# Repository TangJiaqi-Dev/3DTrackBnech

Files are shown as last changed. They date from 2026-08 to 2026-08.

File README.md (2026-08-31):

# 3DTrackBench Documentation

3DTrackBench is a standardized framework for benchmarking Extended Reality (XR) and surgical tracking systems using consumer 3D printers as deterministic motion platforms. In this experiment we would like to validate this accross different 3D printers and international collaborators. Thank you for participating! 

## Core Principle
Consumer 3D printers offer sub-millimeter positioning accuracy ($<0.1$ mm) at low cost. By mounting tracking markers to the extruder and executing a standardized G-code trajectory, the printer serves as a high-fidelity ground truth generator. 

## Validated Metrics
The analysis pipeline quantifies:
* **Static Jitter:** Stability during zero-velocity holds.
* **Spatial Accuracy:** RMSE against analytical ground truth (Linear, Circular, Complex).
* **Latency:** End-to-end system delay (optional module).
* **Robustness:** Tracking loss and drop rates under high-velocity stress.
* **Drift:** Tracking drift over time.

---

# Hardware Setup & Prerequisites

## 1. Required Materials

| Component | Specification | Notes |
| :--- | :--- | :--- |
| **3D Printer** | See '/Materials' for validated printers. | Minimum build volume: $180 \times 180 \times z$ mm. |
| **Tracker** | Any NDI optical tracker. | Custom tracking systems are supported; contact the PI for integration. |
| **Markers** | NDI standard passive marker. | If no official tool, ensure tool registration within NDI software. |
| **Mounting** | Standard NDI mount + 3D printed adapter. | See `/Materials` for models. If standard mounts are incompatible and you need help, contact PI. |
| **Fasteners** | Zip ties. | Required to eliminate mechanical play between extruder and mount. Feel free to use any other rigid option. |

## 2. Adapter Fabrication
1.  **File Selection:** Navigate to `/Materials` and select the adapter matching your printer model and mount type.
2.  **Material:** Use any rigid filament. Recommended but not mandatory to use **Matte Black PLA** to prevent specular reflections from interfering with optical tracking.
3.  **Slicer Settings:** Set infill to a value between 35% and 45% to ensure structural rigidity and use a (outside-)brim to prevent any warping.

## 3. Physical Installation
1.  **Attach Mount:** Secure the printed adapter to the printer head. The connection must be rigid; any vibration or play invalidates metrics. Use zip ties if rigid mounting points are unavailable. Examples of how to fasten the zipties can be found in `/Materials`.
2.  **Affix Markers:** Attach the NDI marker to the adapter using a standard NDI clamp. Ensure the marker plane is **parallel** to the printer's X-axis motion (see reference image).
3.  **Clearance Check:** Manually move the print head to the volume limits to verify zero collision with the frame or bed.

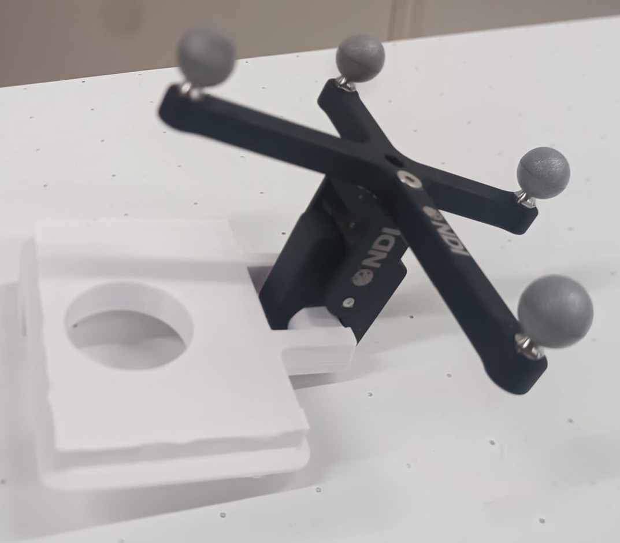
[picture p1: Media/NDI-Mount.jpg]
NDI Mount


## 4. Environmental Standardization
* **Lighting:** Use standard laboratory ceiling lighting. Eliminate direct sunlight.

---

# Benchmark Execution

**WARNING**: Read the readme file in your printer's folder for model-specific safety instructions.

## 5. Tracker Placement
1.  **Printer Stabilization:** Place the printer on a vibration-free platform.
2.  **Load G-code:** Copy the specific G-code files for your printer model to a microSD card or USB drive.
    > **CRITICAL:** Only run G-code generated specifically for your printer model. Mismatched G-code may cause hardware failure.
    > Need a different travel range or feedrate than the shipped file? See [Generating a Custom Benchmark File](#generating-a-custom-benchmark-file) below instead of editing a `.gcode` file by hand.
3.  **Run Placement Script:** Execute `placement.gcode`. This moves the extruder to the center of the tracking volume.
4.  **Align Tracker:** Position the NDI optical tracker perpendicular to the print head at a distance so that the marker is detected in the middle of the NDI standard volume (the smaller box)

## 6. Data Acquisition
1.  **Configure NDI:** Set the NDI recording framerate to the maximum available (minimum $\geq 60$ Hz).
2.  **Execute Benchmark:**
    * Select `Benchmarkv01ext - <your printer> -20251221.gcode` on the printer.
    * **Deselect** automated calibration features (e.g., bed leveling, flow calibration) before starting.
    * Start the NDI recording before starting the execution of the gcode on the printer.
3.  **Completion:** The sequence lasts 6–10 minutes. Stop the NDI recording once the printer signals completion.
4.  **Rerun:** Run the sequence and recording two more times, to end up with 3 measurements.
5.  **Upload the results:** Forward the final results to the PI at `hizirwan.salim@surf.nl

---

# Generating a Custom Benchmark File

The files under `/Materials` trace a fixed 178mm box at a fixed speed sweep. If you need a
different travel range or feedrate — e.g. to test a smaller working volume, or to check
tracking at a narrower speed band — `tools/gcode_generator.py` generates a new `.gcode`
file with those parameters instead of editing one by hand.

```
pip install pyyaml
python tools/gcode_generator.py --printer a1_mini --x-range 40 140 --z-range 40 140 --out out.gcode
```

Supports `a1_mini`, `x1c`, and `h2d` (`--printer`). Requested ranges/speeds are validated
against each printer's physical limits in `printer_profiles.yaml` and rejected if unsafe.
See [tools/README.md](tools/README.md) for the full flag reference.

---

Big thanks for testing 3DTrackBench! Your data is essential for validating this framework. If you run into any issues or have ideas for improvement, don't hesitate to reach out. If you would like to see the results of your own dataset, use the tooling we made below.

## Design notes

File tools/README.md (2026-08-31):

# G-code generator

Generates a 3DTrackBench benchmark `.gcode` file with an adjustable travel
range and speed range, instead of the fixed 180x180mm / F6000-F30000 ranges
baked into the files under `/Materials`.

Supports **A1 mini** (`a1_mini`), **X1 Carbon** (`x1c`), and **H2D** (`h2d`)
— see `printer_profiles.yaml`. A1 mini's toolhead moves in X/Z (Y is the
bed); X1C and H2D are CoreXY and move in X/Y (Z only lifts the bed), so
their range flags are `--x-range`/`--y-range` instead. Adding another
printer means adding a profile entry plus a `templates/<id>/{start,end}.gcode`
pair extracted from a real sliced file for that machine — no code changes.

## Setup

```
pip install pyyaml
```

## Usage

Reproduce the shipped file's default range and speed sweep:

```
python tools/gcode_generator.py --printer a1_mini --out out.gcode
```

Restrict the travel range and/or speed sweep:

```
python tools/gcode_generator.py --printer a1_mini \
  --x-range 40 140 --z-range 40 140 \
  --speed-range 6000 12000 --speed-step 3000 \
  --out out.gcode
```

Flags:
- `--printer` — printer id from `printer_profiles.yaml`: `a1_mini`, `x1c`,
  or `h2d` (default `a1_mini`).
- `--x-range MIN MAX` / `--y-range MIN MAX` / `--z-range MIN MAX` — travel
  range in mm for whichever two axes the printer's toolhead actually moves
  in; passing a range for its bed axis (Y on a1_mini, Z on x1c/h2d) is
  rejected with an error. Omit an axis to center the shipped files' default
  178mm box inside that printer's build volume.
- `--speed-range START END` — feedrate range in mm/min (G-code `F` units,
  e.g. `6000` = 100 mm/s) for the `speed_sweep` phase specifically.
- `--speed-step` — `speed_sweep`'s feedrate step size (default `3000`).
- `--seed` — RNG seed for the scattered-point sections (calibration,
  complex path). Same seed + same range always produces the same points.
- `--out` — output `.gcode` path (required).

`--speed-range`/`--speed-step` only control the `speed_sweep` phase (the
one that repeats a shuttle move at increasing feedrates). The other five
phases each move at their own fixed feedrate — these came from the shipped
A1 mini file with no documented rationale for the specific numbers, so
they're also exposed as flags rather than left hard-coded:

- `--speed-sweep-warmup` — `speed_sweep`'s warm-up feedrate (default `3000`).
- `--calibration-speed` — `calibration`'s corner-move feedrate (default `3000`).
- `--linear-speed` — `linear`'s feedrate (default `6000`).
- `--circular-travel-speed` — `circular`'s approach-move feedrate, before it
  starts tracing the arc (default `2000`).
- `--circular-speed` — `circular`'s arc-tracing feedrate (default `6000`).
- `--complex-speed` — `complex`'s feedrate (default `6000`).
- `--drift-speeds V1 V2 ...` — `drift`'s feedrates, one shuttle pass per
  value (default `3000 6000`).

All feedrate flags are validated against the printer's `max_speed_mm_s` and
rejected if they exceed it, same as `--speed-range`.

Requests that exceed the printer's build volume or max speed
(`printer_profiles.yaml`) are rejected with an error rather than silently
clamped, since running an out-of-range file risks a crash into the frame or
an endstop. A narrower range than the printer's default margin recommends
prints a warning but is still allowed.

## What it generates

The output has the same structure as the shipped files: printer-specific
start/end boilerplate (from `templates/<printer>/`, extracted verbatim from
Bambu Studio) wrapping a benchmark body with these phases, each ending in a
`G4` pause for static hold measurements:

1. **calibration** — static points scattered across the range (jitter).
2. **linear** — a corner-to-corner straight-line sweep (spatial accuracy).
3. **circular** — a full loop around the range's center (spatial accuracy).
4. **speed_sweep** — repeated shuttle moves at each feedrate in the
   configured speed range (robustness at speed).
5. **complex** — scattered points confined to a sub-region (stress test).
6. **drift** — repeated shuttle moves at increasing speed, single-axis then
   diagonal (drift / robustness).

The scattered-point sections use a seeded RNG rather than reproducing the
shipped file's exact coordinates (those came from an unpublished script),
so output is reproducible per seed but not byte-identical to the files
under `/Materials`.

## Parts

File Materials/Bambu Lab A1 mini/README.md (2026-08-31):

# Bambu Lab A1 mini files
Last updated: 11/01/2026

For the Bambu Lab A1, remove the front cover and the yellow rotating extruder indicator. 
If you have the original NDI markers and clamp mount, attach as shown below:

NDI Mount

Shown below is a 'screw on' faceplate for the Atracsys Tindax 305 marker.

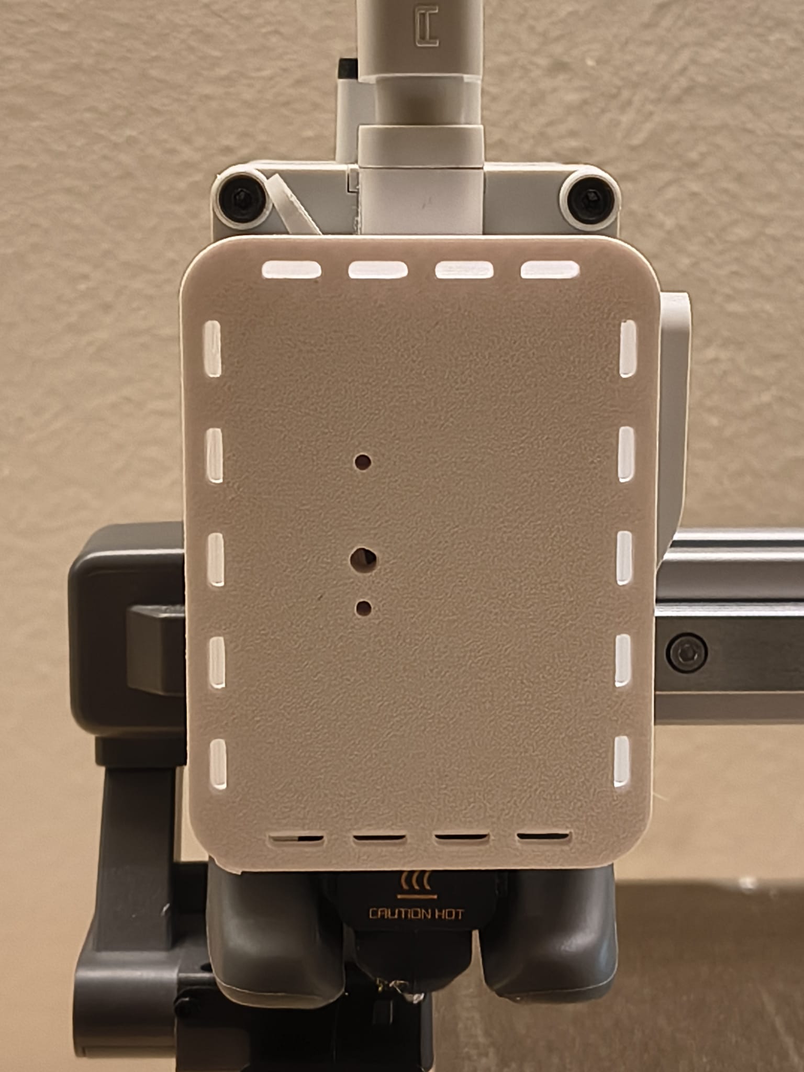
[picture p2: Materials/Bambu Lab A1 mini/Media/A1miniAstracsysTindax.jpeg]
Atracsys Tindax 305 Faceplate


The images below demonstrate how to secure the mount using zip ties. Any method of fixating the markers to the extruder that eliminates all (sub-mm)wobble is sufficient. This is just an example.

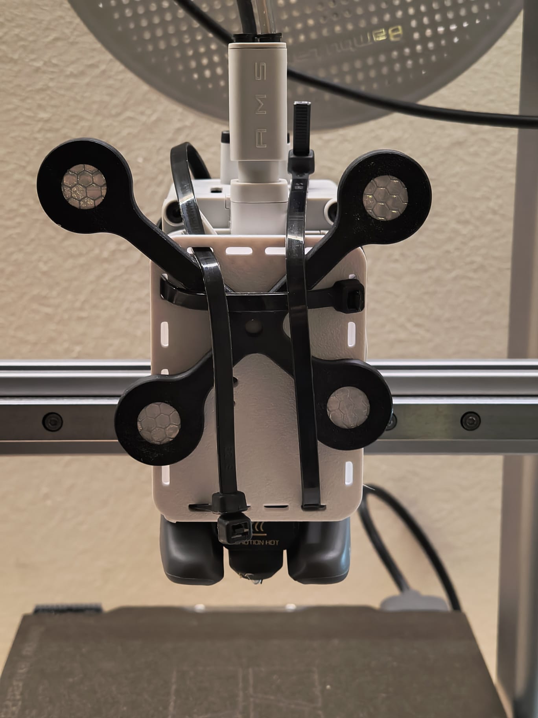
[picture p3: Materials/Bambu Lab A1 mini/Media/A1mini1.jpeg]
Zip Tie Mounting 1

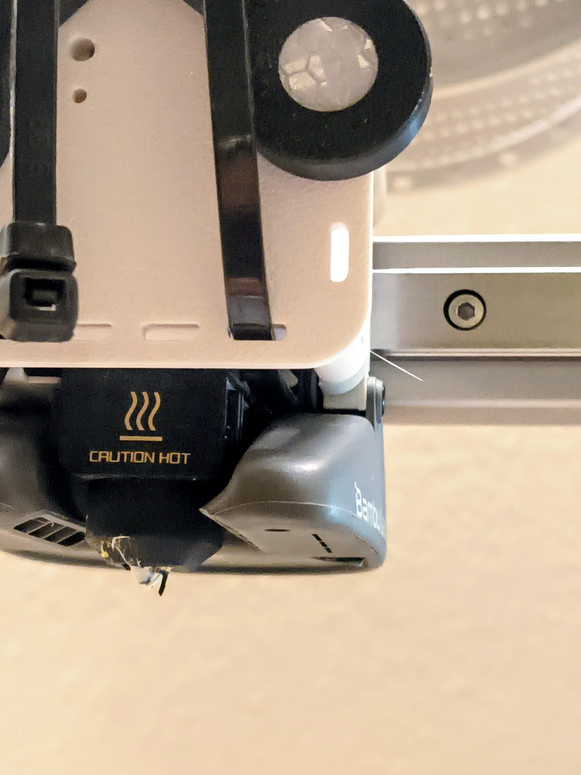
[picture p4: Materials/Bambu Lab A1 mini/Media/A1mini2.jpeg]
Zip Tie Mounting 2

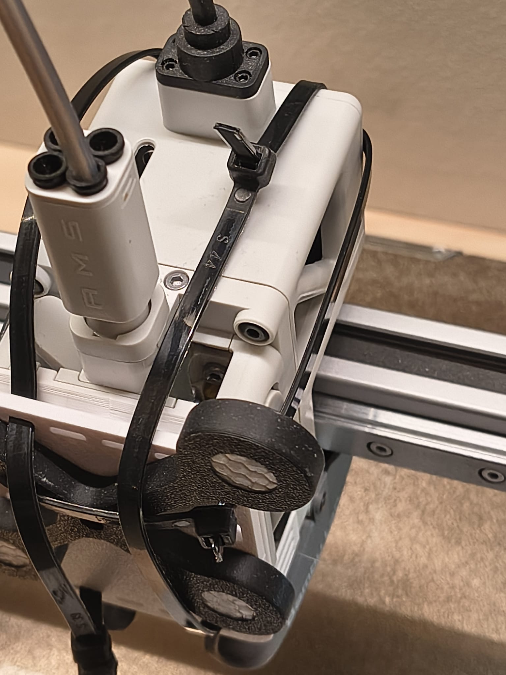
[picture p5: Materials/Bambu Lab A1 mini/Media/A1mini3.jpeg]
Zip Tie Mounting 3


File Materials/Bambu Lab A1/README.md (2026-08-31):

## Bambu Lab A1

**Status: Excluded**

Testing on December 23, 2025, confirmed that the A1 Z-axis motor lacks sufficient power to meet the speed and acceleration requirements of this benchmark. Consequently, this printer is currently unsupported.

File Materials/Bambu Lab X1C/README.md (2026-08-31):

## Bambu Lab X1C Instructions

**CRITICAL WARNING:** The X1C toolhead travels beneath the top frame perimeter. You must follow this setup exactly. Deviating will cause the attached marker to collide with the printer frame.

### Setup and Execution Procedure

1. **Clear Toolhead:** Ensure the toolhead is free of any attachments before starting.
2. **Home Printer:** Select "Home" in the manual control interface.
3. **Verify Position:** Confirm the toolhead is strictly centered on the X and Y axes. Z-height does not matter. **Do not proceed if the head is not centered.**
4. **Maintain Lock:** Do not manually move the toolhead. The motors must remain engaged to hold the center position. The benchmark must always start and end at this coordinate. You cannot rerun 'home' with the attachment in place.
5. **Attach Marker:** Install the marker attachment now.
6. **Execute:** Run the positioning or benchmark script.
7. **Repeat:** Both scripts terminate with the toolhead centered. You may immediately rerun the benchmark from this state.

8. **Teardown:** Remove the marker attachment immediately after testing. **Do not** attempt standard printing or other operations with the attachment in place.

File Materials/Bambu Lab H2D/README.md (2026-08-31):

# Bambu Lab H2D files
Last updated: 30/11/2025

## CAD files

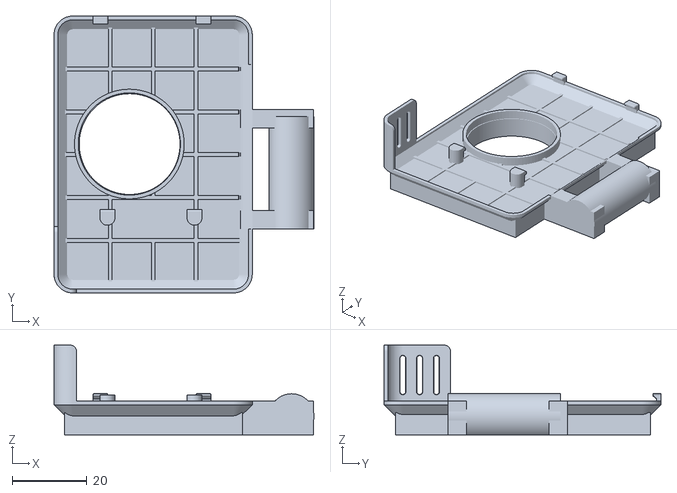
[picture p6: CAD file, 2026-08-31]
Materials/Bambu Lab A1 mini/Attachment_NDI-Official-Clamp.stl
69.5 x 74.0 x 24.0

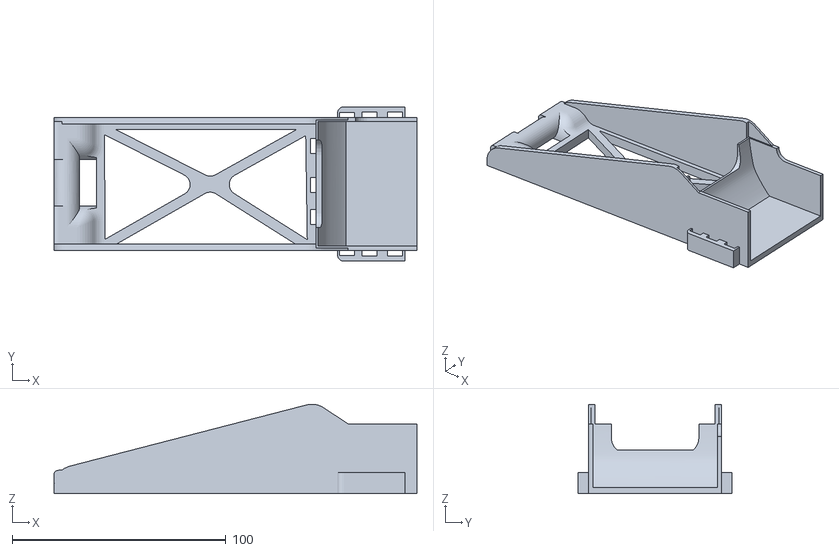
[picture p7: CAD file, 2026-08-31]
Materials/Bambu Lab X1C/Bambu X1C faceplate - for NDI Clamp.stl
170.0 x 72.3 x 41.9

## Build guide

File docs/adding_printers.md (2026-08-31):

# Adding Custom Printers

If your printer is not in `/gcode`, you must generate a compatible motion file.

## Constraints
1.  **Build Volume:** Must accommodate $X: 0 \to 180$, $Y: 0 \to 180$ mm.
2.  **Velocity:** Max speed for benchmark consistency is $500$ mm/s.
3.  **Acceleration:** Set default printer acceleration to $10000$ mm/s².

## Generating G-Code
This is just a placeholder documentation. Will be published when the project is online.

## Submitting New Printers
If you successfully validate a new printer model:
1.  Fork the repository.
2.  Add your G-code to `/gcode`.
3.  Add your profile to `printer_profiles.yaml`.
4.  Submit a Pull Request with the tag `[NEW PRINTER]`.

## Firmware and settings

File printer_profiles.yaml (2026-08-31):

# Registry of printers supported by tools/gcode_generator.py.
#
# motion_axes: the two axes the toolhead itself travels along (the axes the
#   mounted tracker actually moves in). bed_axis is the axis the bed moves on
#   instead, and is not part of the traced benchmark path — its build_volume
#   entry is for reference only and is never range-checked by the generator.
# build_volume: full machine limits in mm, per docs/adding_printers.md.
# default_span: the traced box's edge length (mm) used when a motion axis's
#   --*-range flag is omitted. All shipped files trace the same 178mm box
#   (the smallest supported printer, A1 mini's 180mm bed, minus 1mm margin
#   on each side) centered inside whatever build_volume the printer has —
#   default range per axis = ((build_volume - default_span) / 2, build_volume - that).
# min_margin: mm a requested range should keep clear of the physical travel
#   limit; a tighter request still runs but prints a warning.
# max_speed_mm_s / max_accel_mm_s2: hard ceiling enforced by the generator;
#   requests above these are rejected rather than clamped.

a1_mini:
  display_name: "Bambu Lab A1 mini"
  motion_axes: [X, Z]
  bed_axis: Y
  build_volume: {X: 180, Y: 180, Z: 180}
  default_span: 178
  min_margin: 1
  max_speed_mm_s: 500
  max_accel_mm_s2: 10000
  start_template: templates/a1_mini/start.gcode
  end_template: templates/a1_mini/end.gcode

x1c:
  display_name: "Bambu Lab X1 Carbon"
  motion_axes: [X, Y]
  bed_axis: Z
  # X/Y confirmed from the shipped file's own coordinates (41-219, 51-229 =
  # margin (260-178)/2=41 and (280-178)/2=51). Z is bed-lift, not traced by
  # this benchmark, so its build height is a placeholder and unverified —
  # it never affects generator output.
  build_volume: {X: 260, Y: 280, Z: 256}
  default_span: 178
  min_margin: 1
  max_speed_mm_s: 500
  max_accel_mm_s2: 10000
  start_template: templates/x1c/start.gcode
  end_template: templates/x1c/end.gcode

h2d:
  display_name: "Bambu Lab H2D"
  motion_axes: [X, Y]
  bed_axis: Z
  # X/Y confirmed from the shipped file's own coordinates (61-239 on both =
  # margin (300-178)/2=61). Z build height is an unverified placeholder,
  # same caveat as x1c above.
  build_volume: {X: 300, Y: 300, Z: 300}
  default_span: 178
  min_margin: 1
  max_speed_mm_s: 500
  max_accel_mm_s2: 10000
  start_template: templates/h2d/start.gcode
  end_template: templates/h2d/end.gcode

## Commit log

2026-08-31 Initial commit of 3DTrackBench project
    Import existing documentation, printer materials, and G-code motion files for benchmarking XR/surgical tracking systems using 3D printers.
    [Attachment_NDI-Official-Clamp.stl, Bambu X1C faceplate - for NDI Clamp.stl]
2026-08-31 Add adjustable-range G-code generator for the A1 mini
    Replaces the hard-coded 180x180mm travel range and F6000-F30000 speed
    sweep baked into the shipped .gcode files with a parameterized
    generator (tools/gcode_generator.py), so both the benchmark's spatial
    range and its per-phase feedrates can be set via CLI flags instead of
    edited by hand. Start/end firmware boilerplate is reused verbatim from
    the existing A1 mini file via templates/a1_mini/.
    [printer_profiles.yaml]
2026-08-31 Extend G-code generator to X1C and H2D
    Adds printer profiles and extracted start/end templates for the two
    CoreXY printers (toolhead moves in X/Y, Z lifts the bed), alongside
    the existing A1 mini support.
    Also fixes a bug the extension exposed: the old default_margin field
    assumed a flat 1mm margin when no --*-range flag is given, which was
    only correct for A1 mini. Replaced with default_span (the shared
    178mm traced box) + min_margin (just the too-tight-range warning
    threshold), so the default range correctly centers that box inside
    each printer's actual build volume.
    [printer_profiles.yaml]
